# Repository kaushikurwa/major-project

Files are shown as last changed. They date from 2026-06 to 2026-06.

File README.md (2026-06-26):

# Vision-Guided Fallen Fruit Collection Robot for Orchard Health Monitoring

<p align="center">
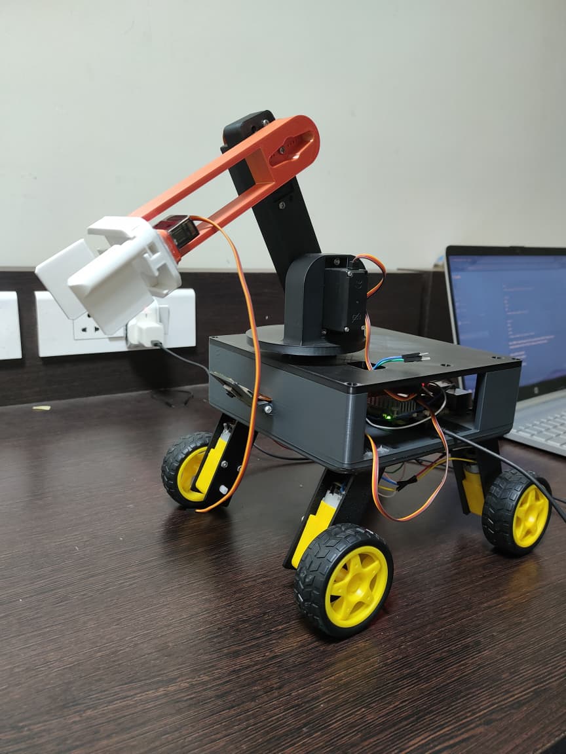
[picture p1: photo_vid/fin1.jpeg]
Robot Front View
  
  &nbsp;&nbsp;
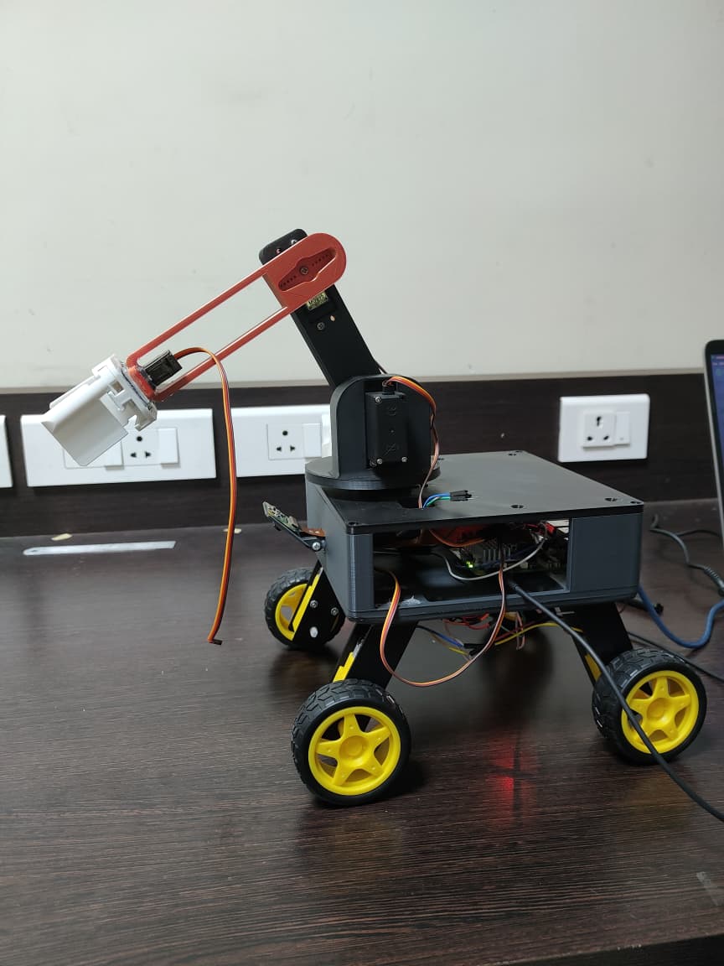
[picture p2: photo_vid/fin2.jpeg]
Robot Side View
  
</p>

<p align="center">
  <b> B.Tech in Robotics & Artificial Intelligence</b><br>
  Department of Robotics & AI, NMAM Institute of Technology, Nitte<br>
  <i>May 2026</i>
</p>

---

##  Overview

This project presents an intelligent semi-autonomous robot designed to detect, collect, classify, and sort fallen tomatoes in orchard environments — without human intervention. It integrates **computer vision**, **deep learning (YOLO11n)**, and **geometric inverse kinematics** on edge hardware to reduce fruit waste and provide real-time orchard health insights.

The robot:
- **Detects** fallen tomatoes using a Raspberry Pi Camera Module 3
- **Classifies** each fruit into one of 6 health categories via a custom-trained YOLO11n Nano model (mAP@0.5 = **89.1%**)
- **Localizes** the fruit using a homography matrix (pixel → real-world mm coordinates)
- **Picks** it using a 3-DOF robotic arm with a parallel-jaw gripper
- **Sorts** it into an Edible bin (ripe/half-ripe) or a Reject bin (diseased/overripe/rot/unripe)

---

##  Demo & Model Weights

> 📦 Full demo videos, dataset, and model weights are hosted on HuggingFace inside Files and versions with different folders:
>
> **[🤗 huggingface.co/kaushikurwa](https://huggingface.co/kaushikurwa)**

---

---

## 📄 Research & IP

<table align="center" width="90%">
  <tr>
    <td width="50%" align="center">
      <h3>🔒 Patent Filed</h3>
      <b>Title:</b> Vision-Guided Fallen Fruit Collection Robot for Orchard Health Monitoring<br><br>
      <b>Applicant:</b> NITTE (Deemed to be University)<br>
      <b>Inventors:</b> Aditya Suresh Kumar · Murali Krish Karkera · Nihal E Praveen · P Kaushik<br>
      <b>Filed via:</b> IPR Cell, NITTE Deemed to be University<br>
      <b>Status:</b> Patent Application Submitted · Publication Requested
    </td>
    <td width="50%" align="center">
      <h3>🗞️ Paper Under Review</h3>
      <b>Title:</b> Design and Development of a Vision-Guided Autonomous Fruit Gleaning and Sorting Robot for Orchard Health Monitoring<br><br>
      <b>Journal:</b> Journal of Automation, Mobile Robotics and Intelligent Systems <a href="https://www.jamris.org">(JAMRIS)</a><br>
      <b>Manuscript ID:</b> ID2185<br>
      <b>Submitted:</b> June 2026
    </td>
  </tr>
</table>

---
## System Architecture

```
Pi Camera Module 3
        │
        ▼
  YOLO11n Inference  ──►  Tomato Detected?
  (Raspberry Pi 5)              │ Yes
        │                       ▼
        │            Homography Matrix
        │           (Pixel → X_mm, Y_mm)
        │                       │
        │                       ▼
        │            Inverse Kinematics
        │         (θ_base, θ_shoulder, θ_elbow)
        │                       │
        │                       ▼
        └──────────►  Arduino Uno (Serial)
                              │
                              ▼
                    15-Step Pick Sequence
                    (1°/step, DONE handshake)
                              │
                    ┌─────────┴─────────┐
                    ▼                   ▼
               LEFT BIN            RIGHT BIN
           (ripe, half ripe)   (overripe, rot,
                                diseased, unripe)
```

---

## AI Model Progression

| Model | Task | Accuracy / mAP |
|---|---|---|
| MobileNetV2 | Classification (4 classes) | 95% |
| ResNet50 | Classification (Fresh/Rotten) | 92% |
| **YOLO11n** ✅ | **Object Detection (6 classes)** | **mAP@0.5 = 89.1%** |

YOLO11n was chosen for its real-time localization capability, critical for deriving coordinates to drive the robotic arm.

### 6 Fruit Health Categories
`diseased` · `half_ripe` · `overripe` · `ripe` · `rotten` · `unripe`

---

## Live Diagnostic Interface

<table align="center" width="90%">
  <tr>
    <td align="center" width="50%">
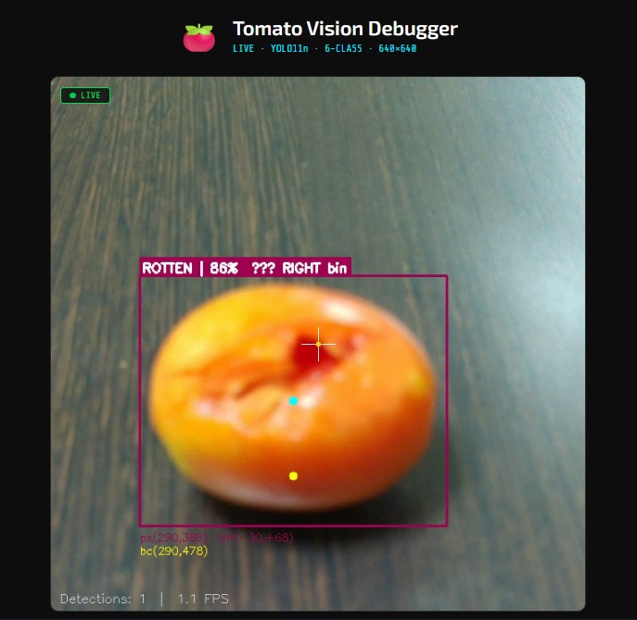
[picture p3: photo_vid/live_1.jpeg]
Rotten Fruit — RIGHT bin
      
    </td>
    <td align="center" width="50%">
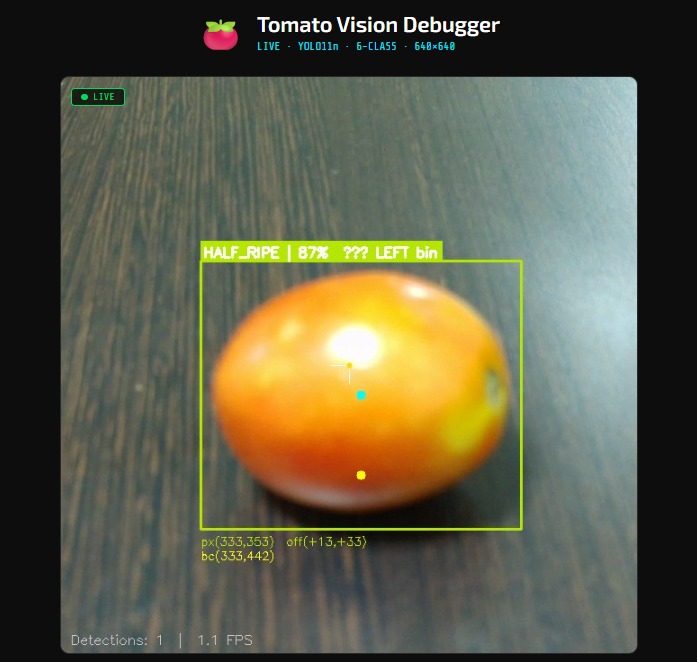
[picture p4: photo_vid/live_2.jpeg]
Half-Ripe Fruit — LEFT bin
      
    </td>
  </tr>
  <tr>
    <td align="center"><sub>ROTTEN | 86% → RIGHT bin</sub></td>
    <td align="center"><sub>HALF_RIPE | 87% → LEFT bin</sub></td>
  </tr>
</table>

A Flask-based web interface streams real-time YOLO11n detections with bounding boxes, confidence scores, pixel-to-mm coordinates, and bin assignment, accessible from any browser on the same network.
---

## Hardware Stack

| Component | Specification | Role |
|---|---|---|
| Main Processor | Raspberry Pi 5 (8GB) | Vision inference + kinematics |
| Microcontroller | Arduino Uno | Motor actuation + handshake |
| Vision Sensor | Pi Camera Module 3 | Image capture |
| Arm Actuators | MG995 & MG90S Servos | 3-DOF arm + gripper |
| Locomotion | 300 RPM BO Motors × 4 | Chassis movement |
| Motor Driver | TB6612FNG | DC motor control |
| Power Regulation | LM2596 Buck Converter | Voltage regulation for servos |

**Total Build Cost: ₹14,334 (~$170 USD)**

---

## Software Stack

| Layer | Technology |
|---|---|
| OS | Ubuntu (Linux) on Raspberry Pi 5 |
| Deep Learning | YOLO11n (Ultralytics) |
| Vision Processing | OpenCV (Homography calibration) |
| High-Level Logic | Python (`auto_picker.py`, `live_vision.py`) |
| Low-Level Control | C++ / Arduino Sketch (`master_listener.ino`) |
| Diagnostics | Flask web server |
| Remote Access | SSH |
| Simulation | Gazebo + RViz (URDF / TF tree) |

---

## Kinematic Model (3-DOF Arm)

**Step 1 — Base Rotation:**
```
θ_base = arctan2(X_mm, Y_mm)
```

**Step 2 — Reach Distance:**
```
Reach = √(X_mm² + Y_mm²)
```

**Step 3 — Elbow Angle (Law of Cosines):**
```
θ_elbow = arccos((D² - L1² - L2²) / (2 × L1 × L2))
```

**Step 4 — Shoulder Angle:**
```
θ_shoulder = arctan2(vertical, Reach) - α
α = arctan2(L2 × sin(θ_elbow), L1 + L2 × cos(θ_elbow))
```

---

## Repository Structure

```
├── src/                    
│   ├── my_robot_bringup
│   └── urdf_description
├── photo_vid/              # Project photos and demo videos
├── orchard_map.pgm         # ROS occupancy map
├── orchard_map.yaml        # Map metadata
└── README.md
```

---

---

## CAD Design

<p align="center">
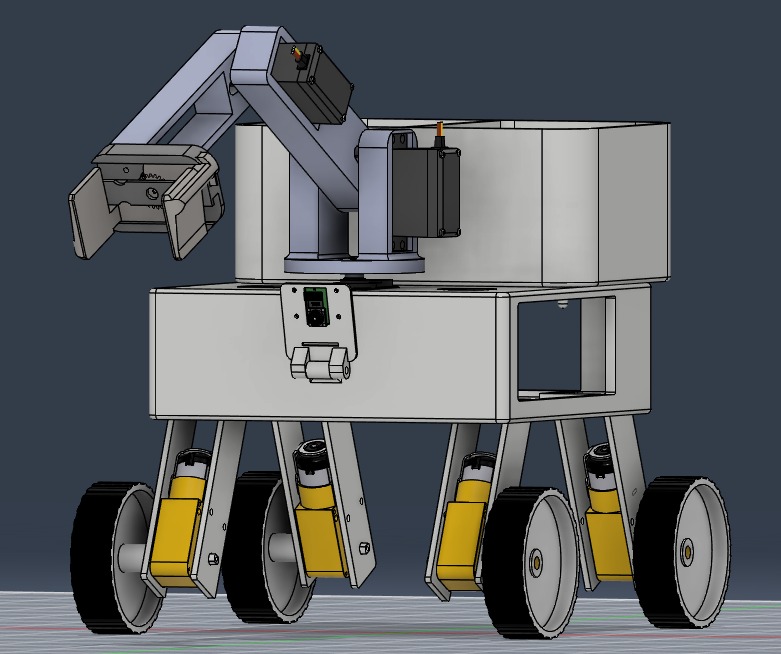
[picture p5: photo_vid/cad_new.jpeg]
3D CAD Model
  
  &nbsp;&nbsp;&nbsp;
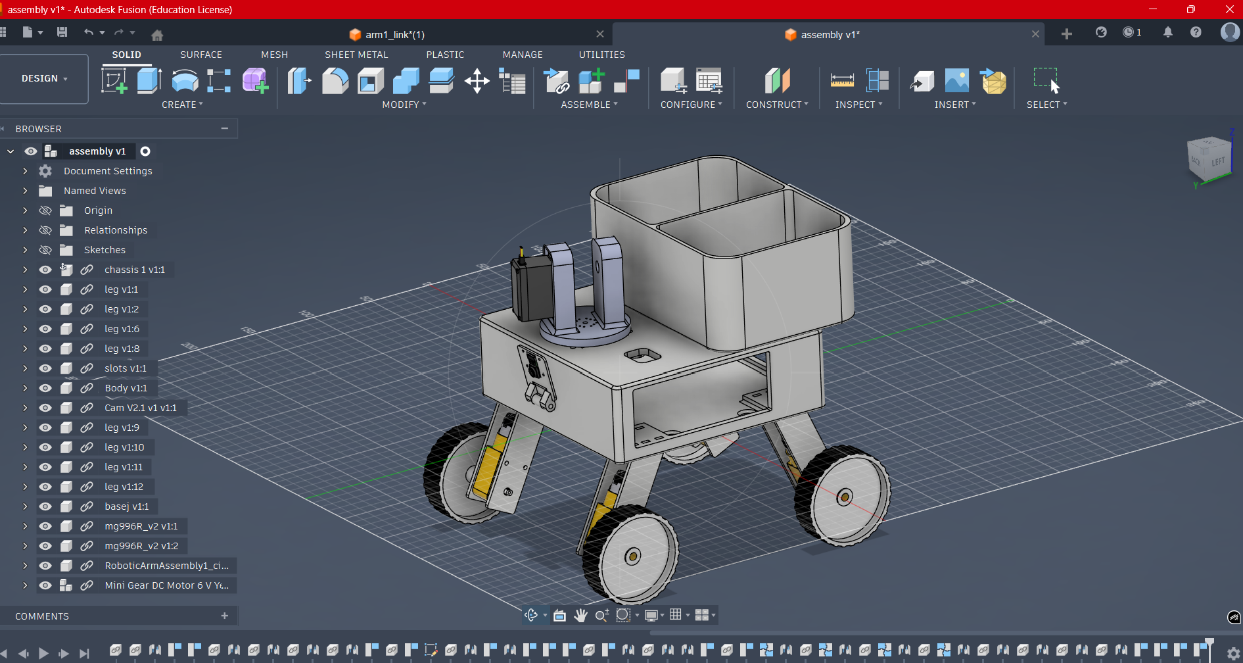
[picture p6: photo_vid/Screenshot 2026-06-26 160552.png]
Fusion 360 CAD Assembly
  
</p>

The full assembly was designed in **Autodesk Fusion 360**, comprising the 4-wheel drive chassis, electronics enclosure, dual-compartment sorting bin, 3-DOF arm links, and parallel-jaw gripper. Each component was parametrically modelled and assembled with joint constraints before fabrication.

---

## Fabrication & Iteration

<p align="center">
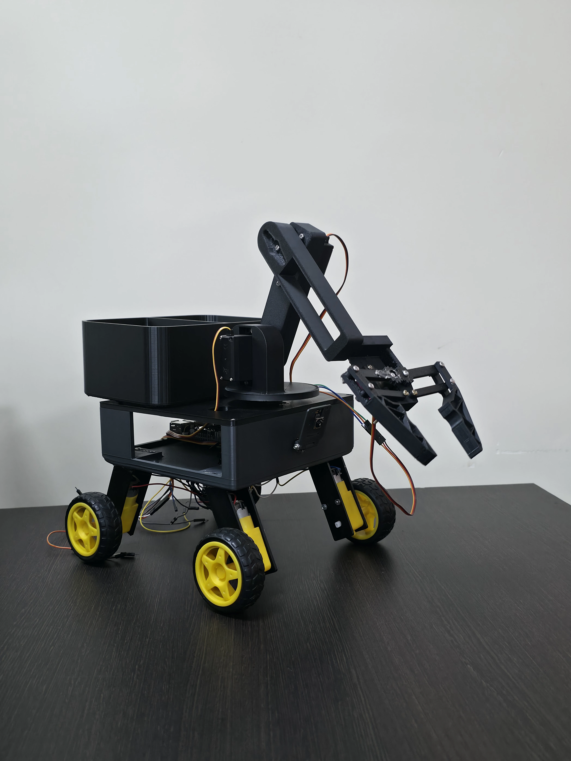
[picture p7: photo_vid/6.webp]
First fabricated robot prototype
  
  &nbsp;&nbsp;
  Final robot — front view
</p>

The first fabricated prototype (left) validated the chassis geometry and arm reach. During initial pick trials, the **end effector servo (MG90S) failed under the load of a tomato**, stripping the gear train. The gripper assembly was redesigned with reinforced mounts and a revised finger geometry, resulting in the final build (right) which completed all pick-and-sort trials successfully.

---

## ROS2 Gazebo Simulation

A full simulation environment was built in **Gazebo (Classic)** with a URDF robot model, differential drive plugin, simulated LiDAR, and a downward-facing camera. The simulation validates the vision and navigation pipeline before deployment on hardware.

### Simulation Stack
| Tool | Role |
|---|---|
| Gazebo Classic | Physics simulation + sensor emulation |
| RViz2 | Robot model visualization + map display |
| slam_toolbox | Online SLAM map generation |
| rqt_image_view | Camera feed inspection |
| ros_gz_bridge | Gazebo ↔ ROS2 topic bridging |

---

### Robot Model & LiDAR Scan

<p align="center">
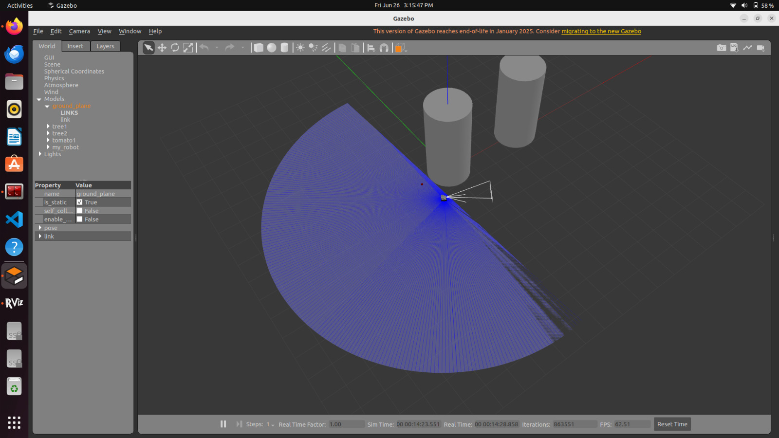
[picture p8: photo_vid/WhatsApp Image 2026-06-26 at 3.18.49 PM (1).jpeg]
Gazebo simulation with LiDAR fan
  
</p>

The robot was spawned in a custom orchard world with cylindrical tree obstacles and a tomato sphere. The blue LiDAR fan indicates that the 2D laser scan is actively sweeping the environment.

---

### Tomato Detection in Simulation

<p align="center">
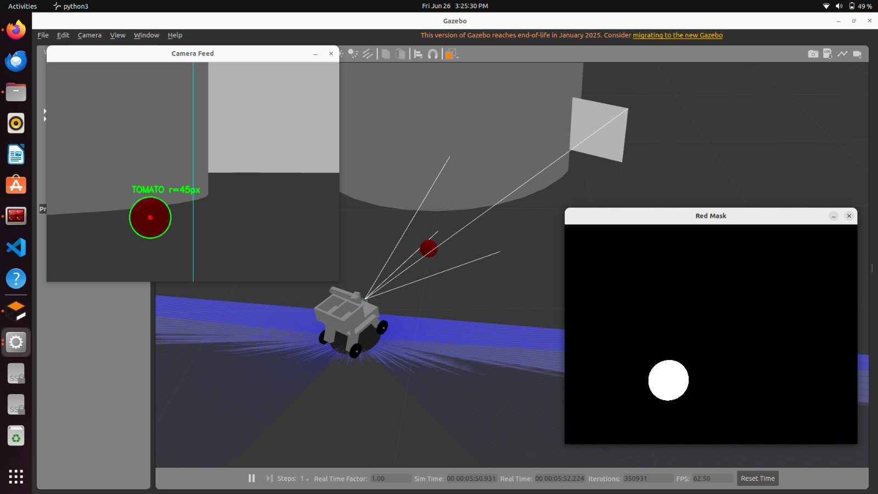
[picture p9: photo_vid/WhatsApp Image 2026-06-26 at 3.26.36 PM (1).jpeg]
Camera feed with tomato detection
  
  &nbsp;&nbsp;
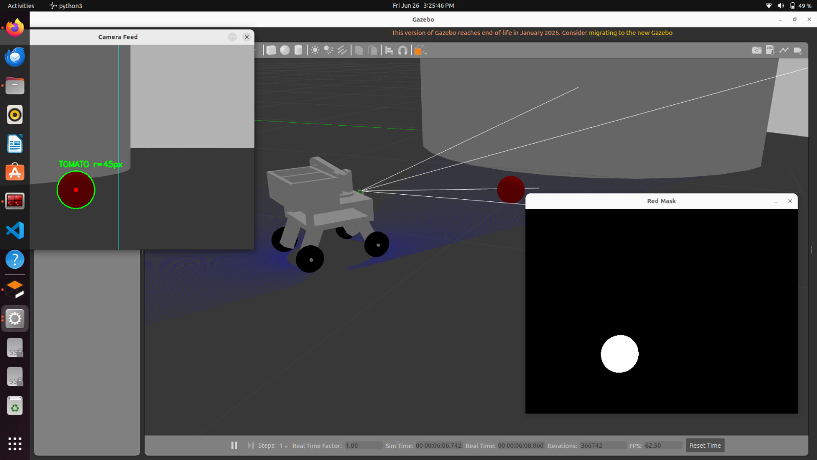
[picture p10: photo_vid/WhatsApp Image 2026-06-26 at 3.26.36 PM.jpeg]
Robot approaching tomato
  
</p>

The `tomato_vision_node` processes the `/camera/image_raw` topic using HSV masking and circularity filtering. When a tomato is detected (radius ≥ 45px), the `tomato_control_node` publishes velocity commands to `/cmd_vel`, steering the robot toward the target until the area threshold is met (≥ 6000px²) and the robot comes to a stop.

---

### SLAM Map Building

<p align="center">
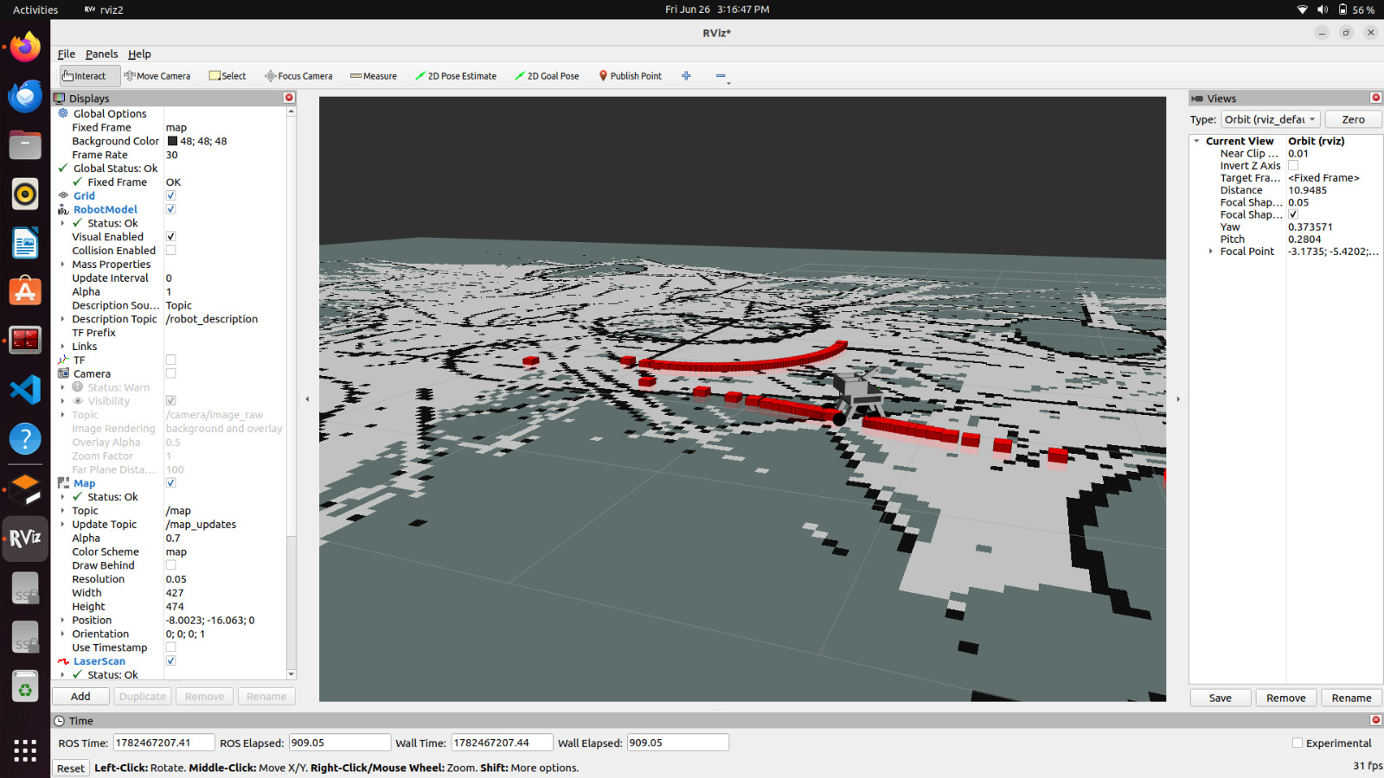
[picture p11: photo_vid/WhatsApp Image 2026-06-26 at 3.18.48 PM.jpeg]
RViz robot model with TF tree
  
  &nbsp;&nbsp;
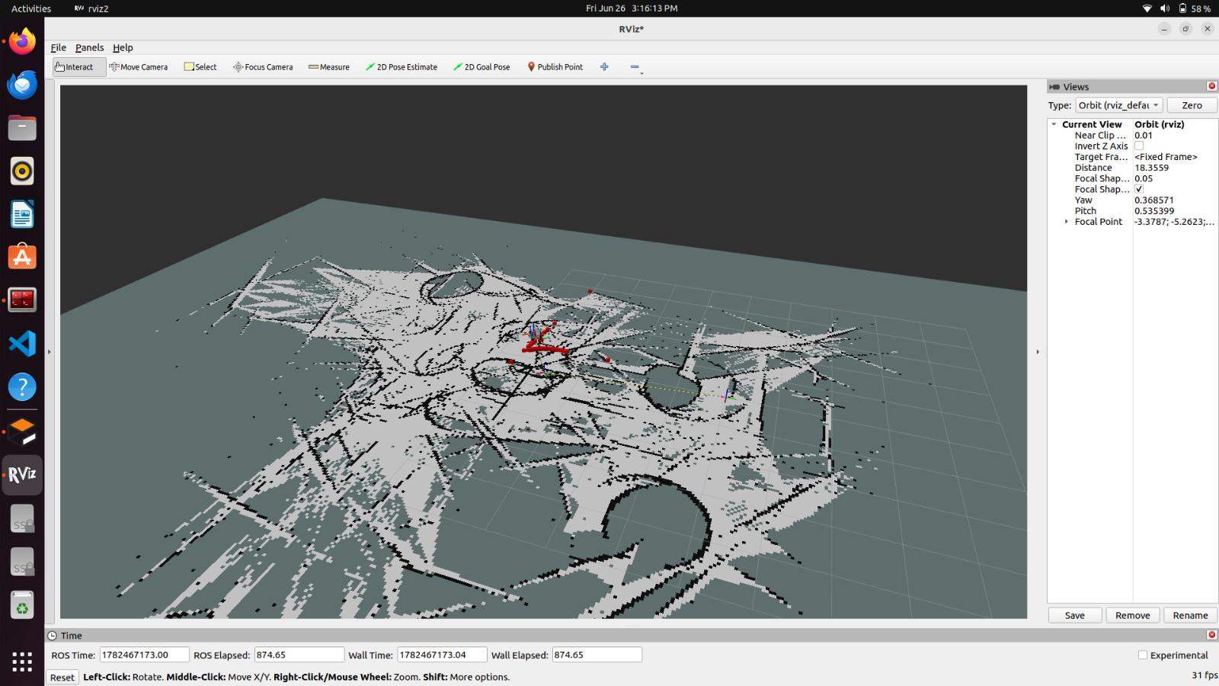
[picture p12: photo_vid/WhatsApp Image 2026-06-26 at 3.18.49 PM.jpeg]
SLAM map top-down view
  
  &nbsp;&nbsp;
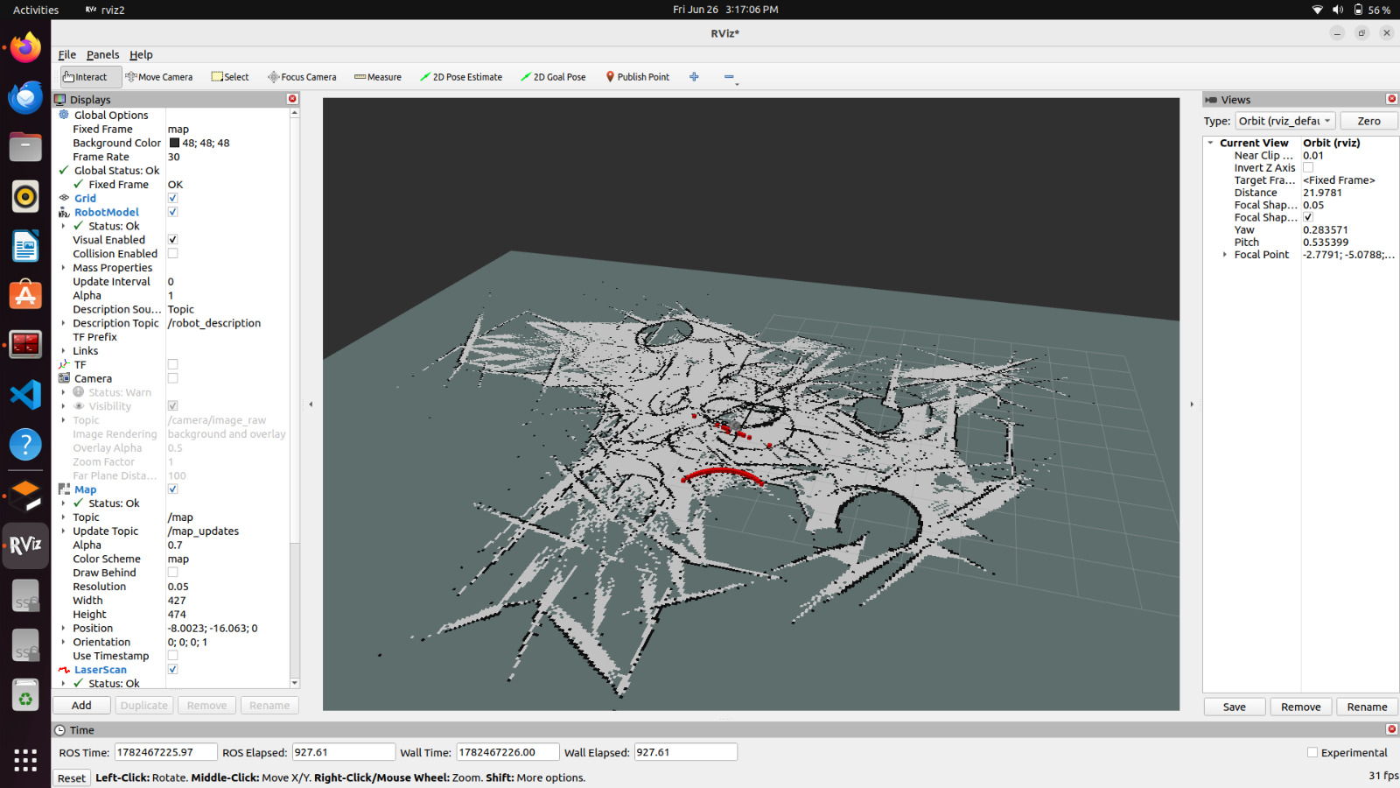
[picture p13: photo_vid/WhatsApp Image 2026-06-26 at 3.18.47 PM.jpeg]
SLAM map 3D view with laser scan
  
</p>

**slam_toolbox** (online asynchronous mode) builds an occupancy grid in real time from the simulated LiDAR. The red laser scan overlay and the TF tree confirm all coordinate frames (`odom → base_footprint → laser`) are correctly bridged between Gazebo and ROS2.

---

### Terminal Output

<p align="center">
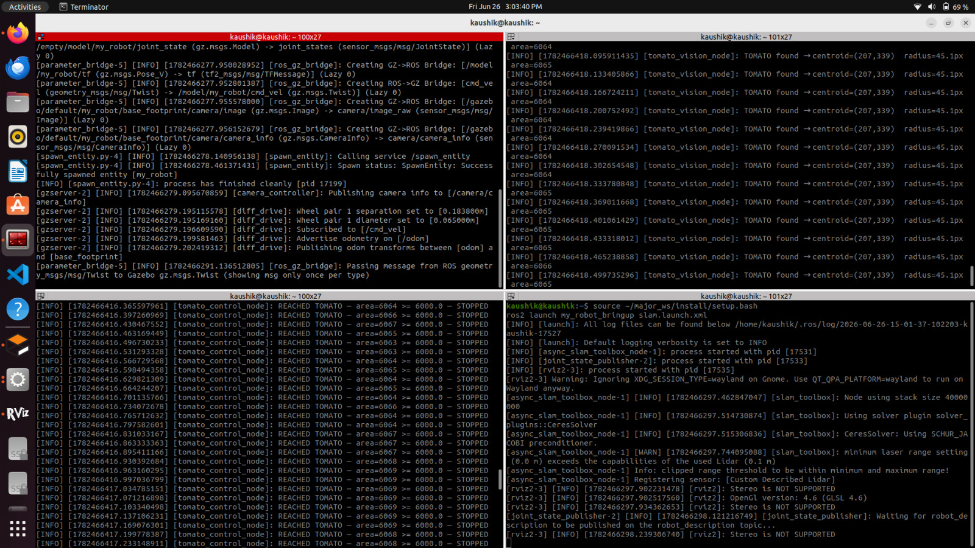
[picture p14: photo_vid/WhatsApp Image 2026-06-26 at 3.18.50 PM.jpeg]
ROS2 terminal output showing nodes
  
</p>

Four terminal panes show the full system running simultaneously: the `ros_gz_bridge`, `tomato_vision_node` reporting centroids and radii, `tomato_control_node` logging STOPPED events when the area threshold is reached, and `slam_toolbox` initializing with CeresSolver.
---

## Project Poster - EXPRO 2025–26

<p align="center">
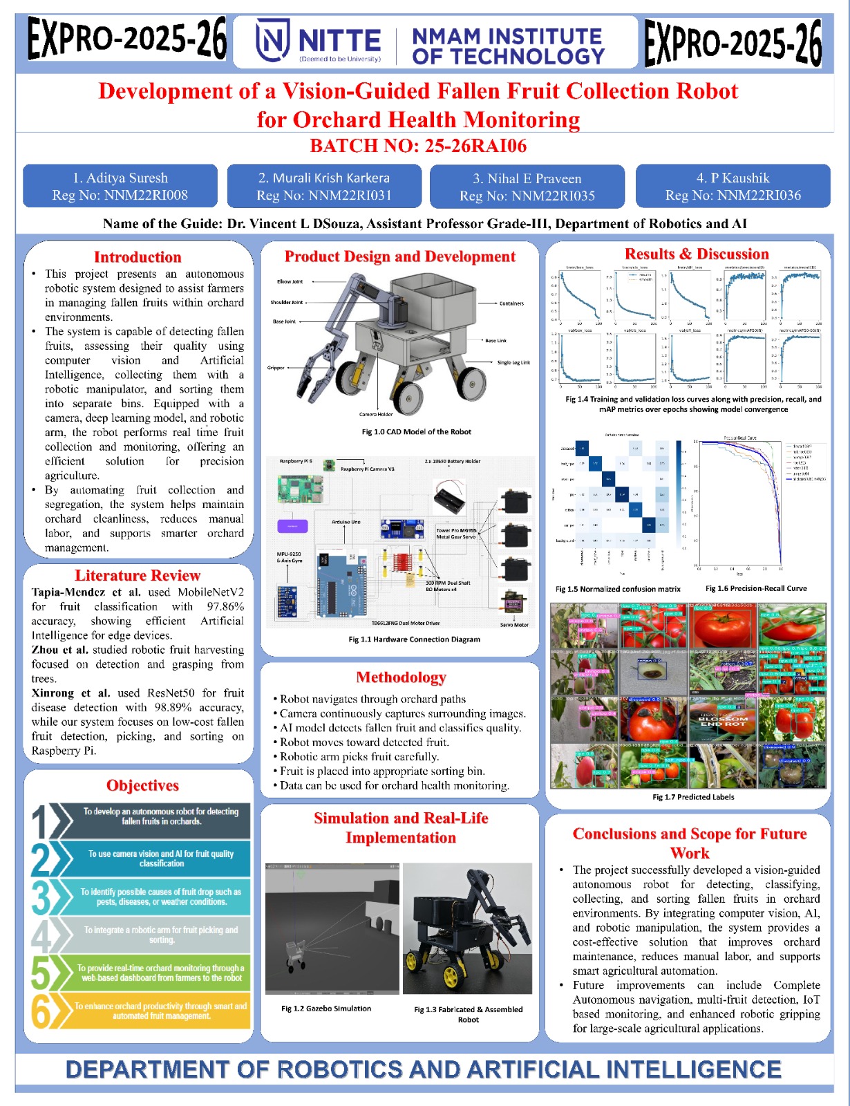
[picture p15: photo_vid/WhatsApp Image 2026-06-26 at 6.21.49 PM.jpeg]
EXPRO 2025-26 Project Poster
  
</p>

Presented at **EXPRO 2025–26**, the annual project exposition at NMAM Institute of Technology, Nitte.

---
## Results Summary

- **YOLO11n mAP@0.5:** 0.891 across 6 classes
- **Best class AP:** Overripe → 0.947 | Ripe → 0.915
- **Confusion matrix highlights:** 89% Ripe, 87% Overripe, 85% Diseased correctly classified
- **Turnitin Similarity:** 9% (with bibliography filtered)
- **Pick routine:** 15-step sequence with degree-by-degree actuation and DONE handshake

---

## Future Work

1. Full autonomous navigation using **Monocular Visual SLAM**
2. **3D imaging / NIR sensors** for depth-aware detection
3. Real-time **orchard health mapping** from fruit coordinate logs
4. **Self-docking recharge station** for extended uptime
5. **Mesh networking** for multi-robot coordination
6. **Software camera stabilization** to handle uneven terrain vibrations

---

## License

This project was submitted in partial fulfillment of the requirements for the award of **B.Tech in Robotics & Artificial Intelligence** at NMAM Institute of Technology, Nitte (Deemed to be University), May 2026.

---

<p align="center">
  Made by Team NNM22RI NMAMIT, Nitte
</p>

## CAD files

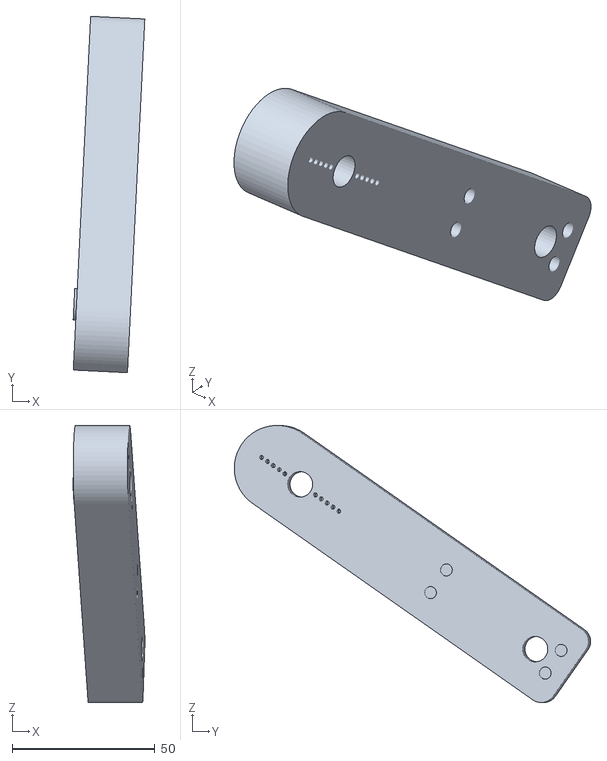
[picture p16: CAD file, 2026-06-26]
src/urdf_description/meshes/arm1_link_1.stl
25.1 x 124.8 x 97.0

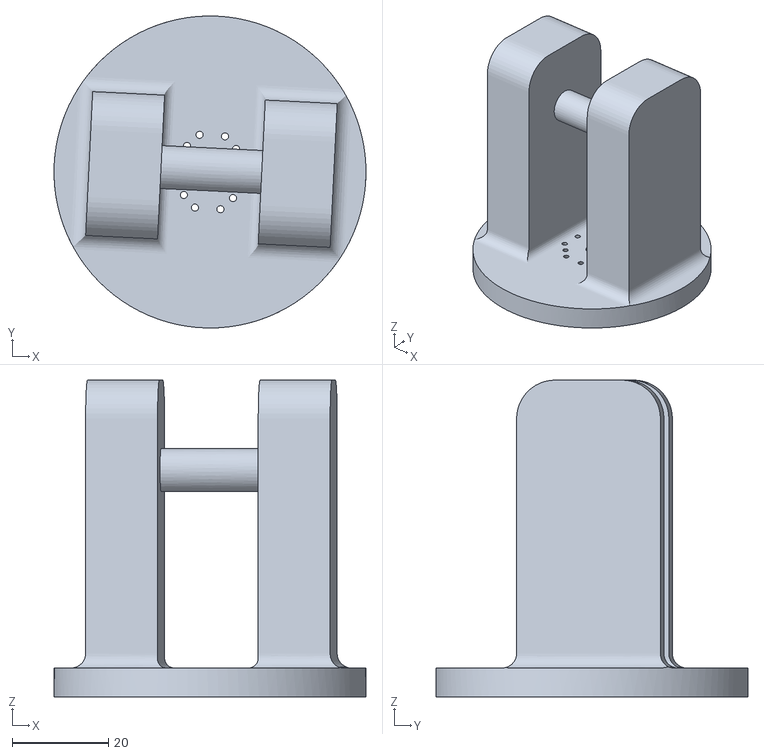
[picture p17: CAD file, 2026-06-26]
src/urdf_description/meshes/armbase_link_1.stl
65.0 x 65.0 x 66.0

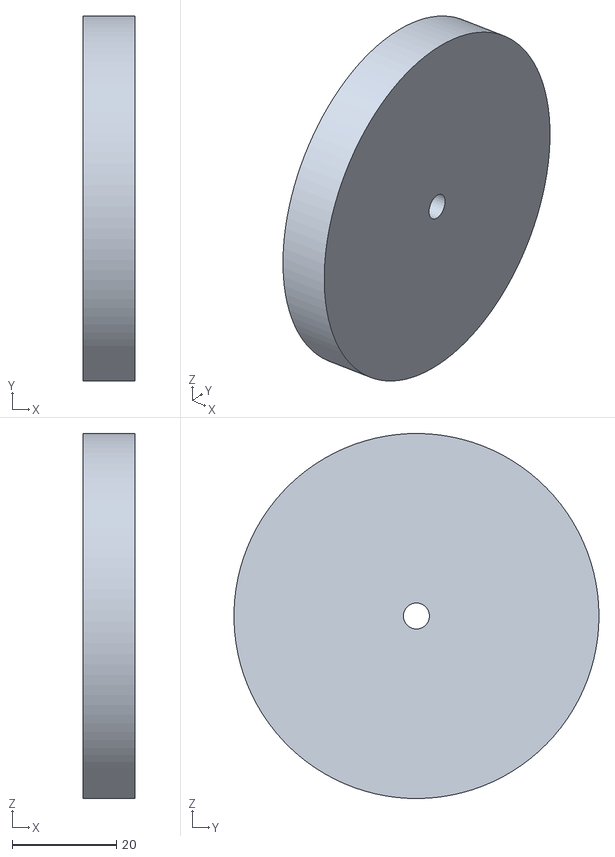
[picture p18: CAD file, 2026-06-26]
src/urdf_description/meshes/right_wheel2_1.stl
10.0 x 70.0 x 70.0

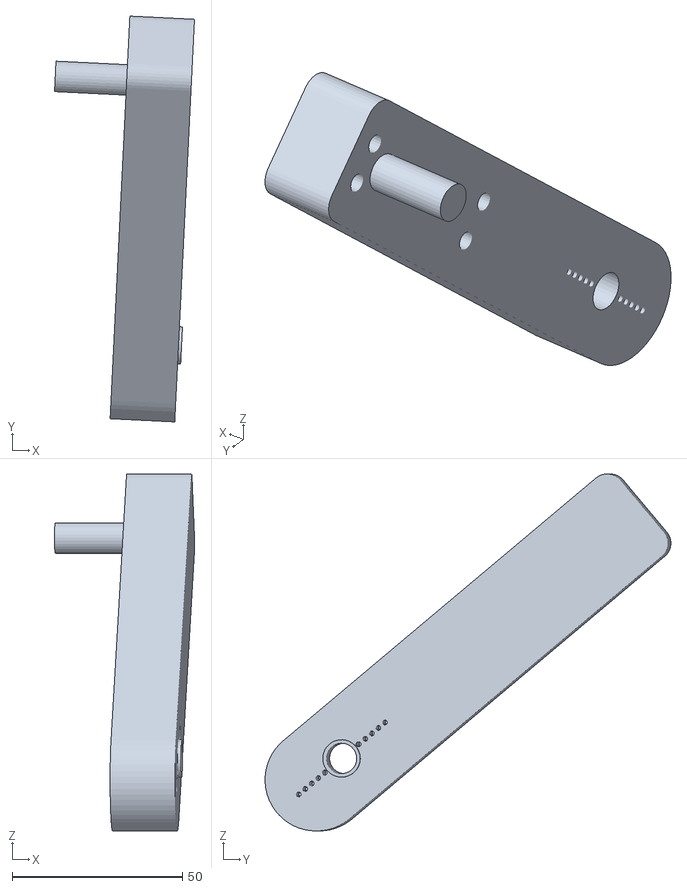
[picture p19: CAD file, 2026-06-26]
src/urdf_description/meshes/arm2_link_1.stl
41.1 x 119.1 x 104.8

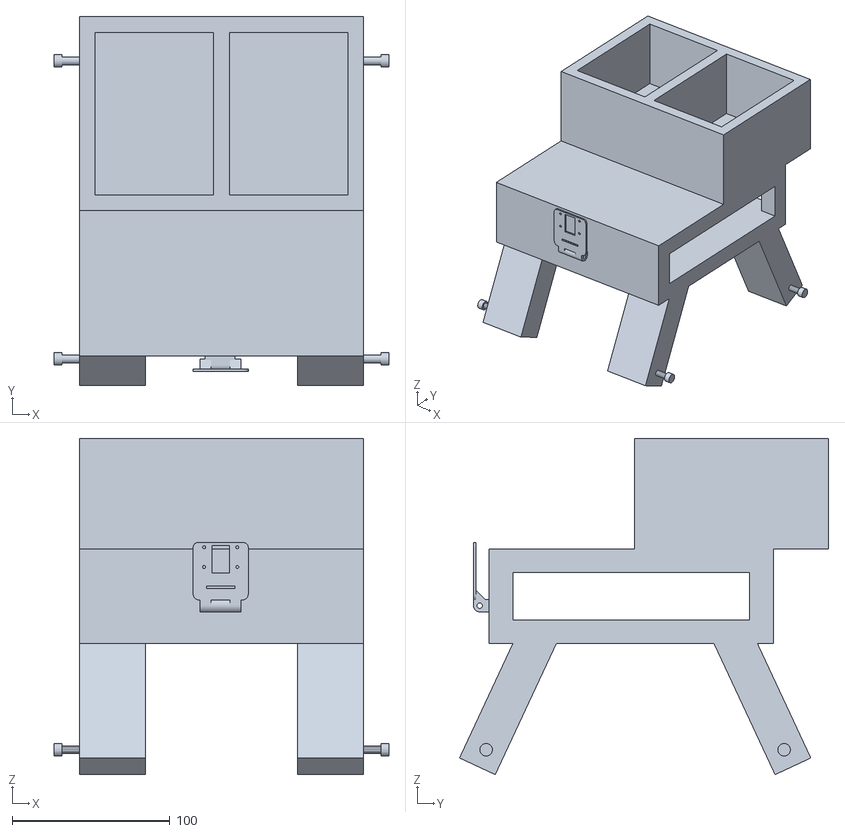
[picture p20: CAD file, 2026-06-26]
src/urdf_description/meshes/base_link.stl
212.0 x 233.8 x 213.1

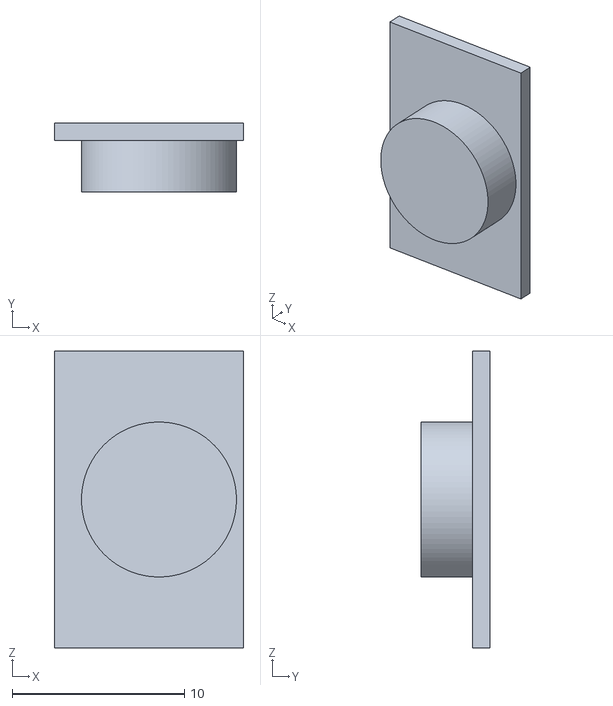
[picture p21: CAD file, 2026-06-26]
src/urdf_description/meshes/cam_link_1.stl
11.0 x 4.00 x 17.2

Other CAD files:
src/urdf_description/meshes/right_wheel1_1.stl
src/urdf_description/meshes/left_wheel2_1.stl
src/urdf_description/meshes/left_wheel1_1.stl

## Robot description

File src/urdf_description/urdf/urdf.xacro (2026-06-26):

<?xml version="1.0" ?>
<robot name="my_robot" xmlns:xacro="http://www.ros.org/wiki/xacro">

<xacro:include filename="materials.xacro" />
<xacro:include filename="camera.xacro" />
<xacro:include filename="drive_control.xacro" />
<xacro:include filename="lidar.xacro" />

<link name="base_footprint"/>

<link name="base_link">
  <inertial>
    <origin xyz="-9.068721438447272e-07 0.016818956769741884 0.13757244036998353" rpy="0 0 0"/>
    <mass value="16.129870302720548"/>
    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
  </inertial>
  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
</link>

<link name="cam_link_1">
  <inertial>
    <origin xyz="0.00029040885549365706 -0.0010028948136634602 -0.00862499966472527" rpy="0 0 0"/>
    <mass value="0.0029877236299923403"/>
    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
  </inertial>
  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
</link>

<link name="left_wheel1_1">
  <inertial>
    <origin xyz="0.004999999999999963 2.695303707445085e-07 3.8435314280577115e-07" rpy="0 0 0"/>
    <mass value="0.300562059655161"/>
    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
  </inertial>
  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
</link>

<link name="left_wheel2_1">
  <inertial>
    <origin xyz="0.0049999999999999906 -2.6953037318699913e-07 3.8435314281271005e-07" rpy="0 0 0"/>
    <mass value="0.300562059655161"/>
    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
  </inertial>
  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
</link>

<link name="right_wheel1_1">
  <inertial>
    <origin xyz="-0.004999999999999935 2.6953037327026586e-07 3.8435314292373235e-07" rpy="0 0 0"/>
    <mass value="0.300562059655161"/>
    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
  </inertial>
  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
</link>

<link name="right_wheel2_1">
  <inertial>
    <origin xyz="-0.004999999999999963 -2.6953037078614184e-07 3.8435314279883226e-07" rpy="0 0 0"/>
    <mass value="0.3005620596551611"/>
    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
  </inertial>
  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
</link>

<link name="armbase_link_1">
  <inertial>
    <origin xyz="0.00022108018193362611 0.00038730930499579486 0.027399267414813827" rpy="0 0 0"/>
    <mass value="0.5767027085005034"/>
    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
  </inertial>
  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
</link>

<link name="arm1_link_1">
  <inertial>
    <origin xyz="0.007283258896485331 -0.04475419067069337 0.031049988379295457" rpy="0 0 0"/>
    <mass value="0.5865146005990974"/>
    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
  </inertial>
  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
</link>

<joint name="armbase_link_base_link" type="continuous">
  <origin xyz="0.0 -0.044 0.162294" rpy="0 0 0"/>
  <parent link="base_link"/>
  <child link="armbase_link_1"/>
  <axis xyz="-0.0 0.0 1.0"/>
</joint>

<joint name="arm1_link_armbase_link" type="revolute">
  <origin xyz="-0.010191 0.001033 0.047297" rpy="0 0 0"/>
  <parent link="armbase_link_1"/>
  <child link="arm1_link_1"/>
  <axis xyz="0.9988 -0.048965 -0.0"/>
  <limit upper="0.349066" lower="-2.181662" effort="100" velocity="100"/>
</joint>

<joint name="cam_link_base_link_joint" type="fixed">
  <origin xyz="-0.0005 -0.09925 0.164544" rpy="0 0 -1.5708"/>
  <parent link="base_link"/>
  <child link="cam_link_1"/>
</joint>

<joint name="base_footprint_to_base_link_joint" type="fixed">
  <origin xyz="0 0 0" rpy="0 0 0"/>
  <parent link="base_footprint"/>
  <child link="base_link"/>
</joint>


<joint name="left_wheel1_base_link_joint" type="continuous">
  <origin xyz="0.09 -0.091905 0.035" rpy="0 0 0"/>
  <parent link="base_link"/>
  <child link="left_wheel1_1"/>
  <axis xyz="1.0 0.0 0.0"/>
</joint>

<joint name="left_wheel2_base_link_joint" type="continuous">
  <origin xyz="0.09 0.096905 0.035" rpy="0 0 0"/>
  <parent link="base_link"/>
  <child link="left_wheel2_1"/>
  <axis xyz="1.0 0.0 0.0"/>
</joint>

<joint name="right_wheel1_base_link_joint" type="continuous">
  <origin xyz="-0.09 -0.091905 0.035" rpy="0 0 0"/>
  <parent link="base_link"/>
  <child link="right_wheel1_1"/>
  <axis xyz="1.0 0.0 0.0"/>
</joint>

<joint name="right_wheel2_base_link_joint" type="continuous">
  <origin xyz="-0.09 0.096905 0.035" rpy="0 0 0"/>
  <parent link="base_link"/>
  <child link="right_wheel2_1"/>
  <axis xyz="1.0 0.0 0.0"/>
</joint>

</robot>
